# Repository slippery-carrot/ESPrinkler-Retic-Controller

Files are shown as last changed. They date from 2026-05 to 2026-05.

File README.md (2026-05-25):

# 🌱 ESPrinkler Retic Controller

An open-source, ESP32-based smart irrigation controller built with **ESPHome** and designed for seamless integration with **Home Assistant**.

ESPrinkler gives you full local control over your irrigation system—no cloud services, no subscriptions, and no reliance on external servers. All schedules are stored directly on the device, ensuring your system continues to run even if Home Assistant or network connectivity becomes unavailable.

---

## 🚀 Features

- Fully local operation (no cloud dependencies)  
- Home Assistant integration via ESPHome  
- Standalone operation with onboard schedule storage  
- Solid-state design with optically isolated outputs  
- Control up to **8 irrigation zones + pump/master valve**  
- Support for **up to 3 independent watering programs**  
- Flexible scheduling:
  - Day-of-week control  
  - Up to 4 start times per program  
  - Configurable zone durations and repeat cycles  
- LED indicators for system status and outputs  

---

## 🧠 How It Works

ESPrinkler operates using up to **three independent watering programs**, each of which defines:

- When watering occurs (days + start times)  
- Which zones are active  
- How long each zone runs  
- Whether the cycle repeats  

All configuration is done through **Home Assistant entities**, and once configured, the controller runs autonomously.

⚠️ Programs **do not prevent overlap automatically**, so you must ensure schedules don’t conflict.

---

## 🏗️ Hardware Overview

The controller is built around an **ESP32 (ESP32-DevKitC compatible)** and a custom PCB designed for irrigation control.

Key hardware characteristics:

- Compatible with 24VAC reticulation systems
- Solid-state solenoid switching  
- Isolated AC/DC sections
- Fused solenoid power output
- Terminal block wiring for:
  - Power input  
  - Pump/master valve  
  - 8 irrigation zones  
- Optional external LEDs for:
  - Wi-Fi status  
  - System status  

For full specifications, wiring diagrams, and pinouts, see:  
**[Hardware Specifications Wiki](../../wiki/Hardware-Specifications)**

---

## ⚡ Requirements

To build and use ESPrinkler, you’ll need:

- ESP32 Dev Board (ESP32-DevKitC compatible)  
- ESPrinkler PCB (assembled or DIY)  
- 24VAC transformer (~30VA recommended)  
- Fuse (M205 1A Quick Blow)  
- Suitable enclosure  
- Wiring/connectors for your installation  
- Home Assistant with ESPHome installed  

---

## 🛠️ Getting Started

### 1. Set Up ESPHome

Install and configure ESPHome in Home Assistant:  
https://esphome.io/guides/getting_started_hassio/

---

### 2. Prepare Firmware

- Copy the provided `secrets.yaml` values into your ESPHome setup  
- Import the `retic-controller.yaml` file into ESPHome (Add new device -> Import from file) 
- Update the substitutions (Wi-Fi, API key, device name, etc.)  

---

### 3. Flash the Device

- Click the 3 dots under the new configuration
- Click "install" and follow your preferred method to flash your ESP32
- I recommend choosing "manual download" and then navigate to [ESPHome Web](https://web.esphome.io/) to flash your device using the binary file
- Once flashed, the device will appear in Home Assistant

---

### 4. Wire the Hardware

- Connect 24VAC input  
- Connect solenoids (zones + common)  
- Install fuse  
- Optional: connect status LEDs  

⚠️ **Warning:** This involves working with mains/low-voltage AC systems. Follow all relevant electrical safety standards and regulations.
👉 See the **[Hardware Specifications Wiki](../../wiki/Hardware-Specifications)** for full wiring details and pinouts.

---

### 5. Configure in Home Assistant

Once the device is online:

- Enable one or more programs  
- Set watering days  
- Configure start times  
- Enable zones and durations
- An example [dashboard page .yaml file](https://github.com/slippery-carrot/ESPrinkler-Retic-Controller/blob/main/ESPHome/ESPrinkler_Dashboard_Example.yaml) has been provided as an example layout in Home Assistant

⚠️ **NOTE:** The example dashboard yaml uses [Mushroom Cards](https://github.com/piitaya/lovelace-mushroom), so make sure to install that if you want it to function.
👉 See the **[Home Assistant Entities Wiki](../../wiki/Home-Assistant-Entities)** for a full breakdown of all controls, sensors, and configuration options.

---

## 🌿 Program Basics

Each program requires:

- ✅ Program enabled  
- ✅ At least one watering day  
- ✅ At least one start time  
- ✅ At least one active zone with duration  

Optional settings:

- Repeat cycles (repeat full zone sequence)  

---

## 🏠 Home Assistant Integration

ESPrinkler exposes a full set of:

- **Controls** (start/stop, enable program, pause)  
- **Sensors** (current zone, time remaining, next cycle)  
- **Configuration entities** (days, times, durations, repeats)  
- **Diagnostics** (Wi-Fi signal, uptime, firmware, etc.)  

👉 Full details here:  
**[Home Assistant Entities Wiki](../../wiki/Home-Assistant-Entities)**

---

## 🧩 Project Structure

- Firmware: ESPHome YAML configuration and secrets example, including example dashboard layout  
- Hardware: Custom PCB design in KiCad and production files
- Documentation:
  - README (this file)  
  - Hardware Wiki  
  - Home Assistant Wiki  

---

## ⚠️ Important Notes

- Programs **can overlap** if configured incorrectly—this is not automatically prevented  
- Default start times may be active—always verify configuration  
- Ensure the transformer you choose is correctly sized for your solenoid load
- Always use appropriate fuse protection

---

## 🪰 Limitations, Issues, and Bugs
 - ESPrinkler requires connection to home assistant at least once in order to set its internal clock. Without this, it has no reference to the current time and date

## 🔗 Documentation

- 📘 **[Hardware Specifications Wiki](../../wiki/Hardware-Specifications)** – Pinouts, wiring, electrical specs  
- 📗 **[Home Assistant Entities Wiki](../../wiki/Home-Assistant-Entities)** – Entities, controls, automation  

---

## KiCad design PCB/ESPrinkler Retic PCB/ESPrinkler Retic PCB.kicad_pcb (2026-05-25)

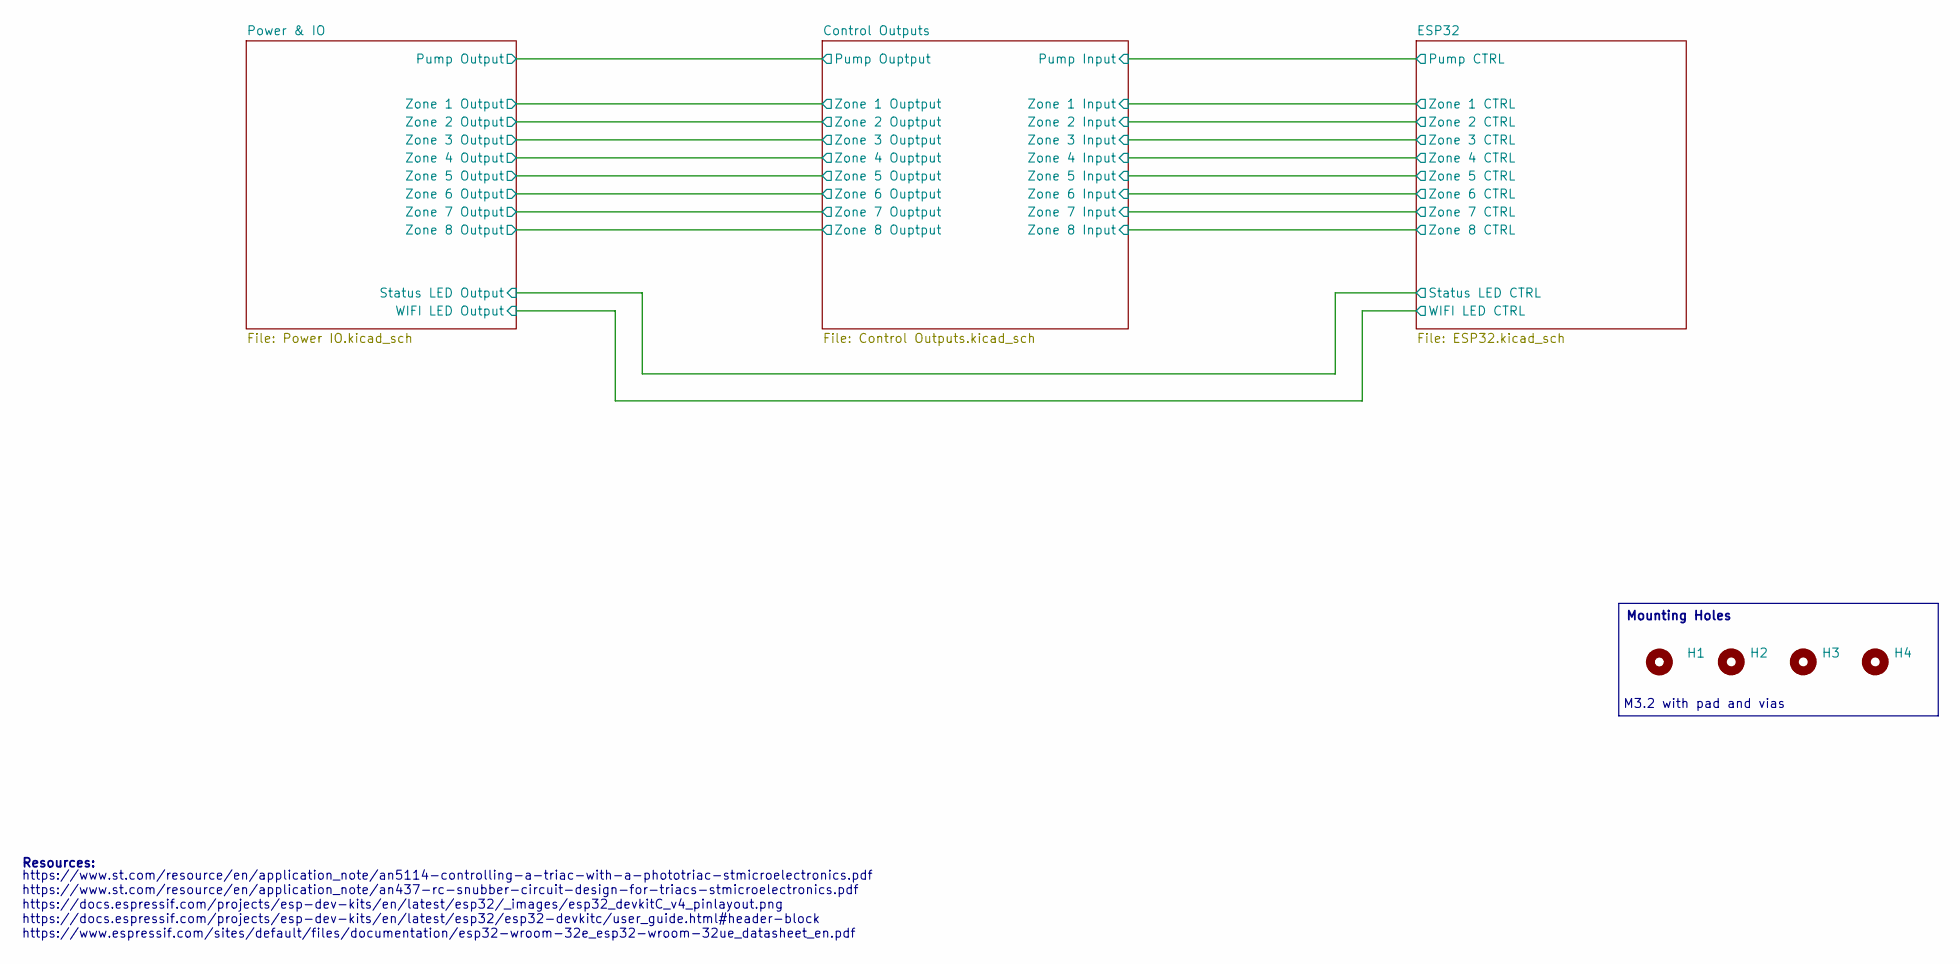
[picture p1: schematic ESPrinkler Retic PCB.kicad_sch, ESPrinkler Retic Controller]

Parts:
H1, H2, H3, H4: MountingHole; MountingHole_3.2mm_M3_Pad_Via

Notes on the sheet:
https://www.st.com/resource/en/application_note/an5114-controlling-a-triac-with-a-phototriac-stmicroelectronics.pdf https://www.st.com/resource/en/application_note/an437-rc-snubber-circuit-design-for-triacs-stmicroelectronics.pdf https://docs.espressif.com/projects/esp-dev-kits/en/latest/esp32/_ima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
M3.2 with pad and vias
Resources:
Mounting Holes

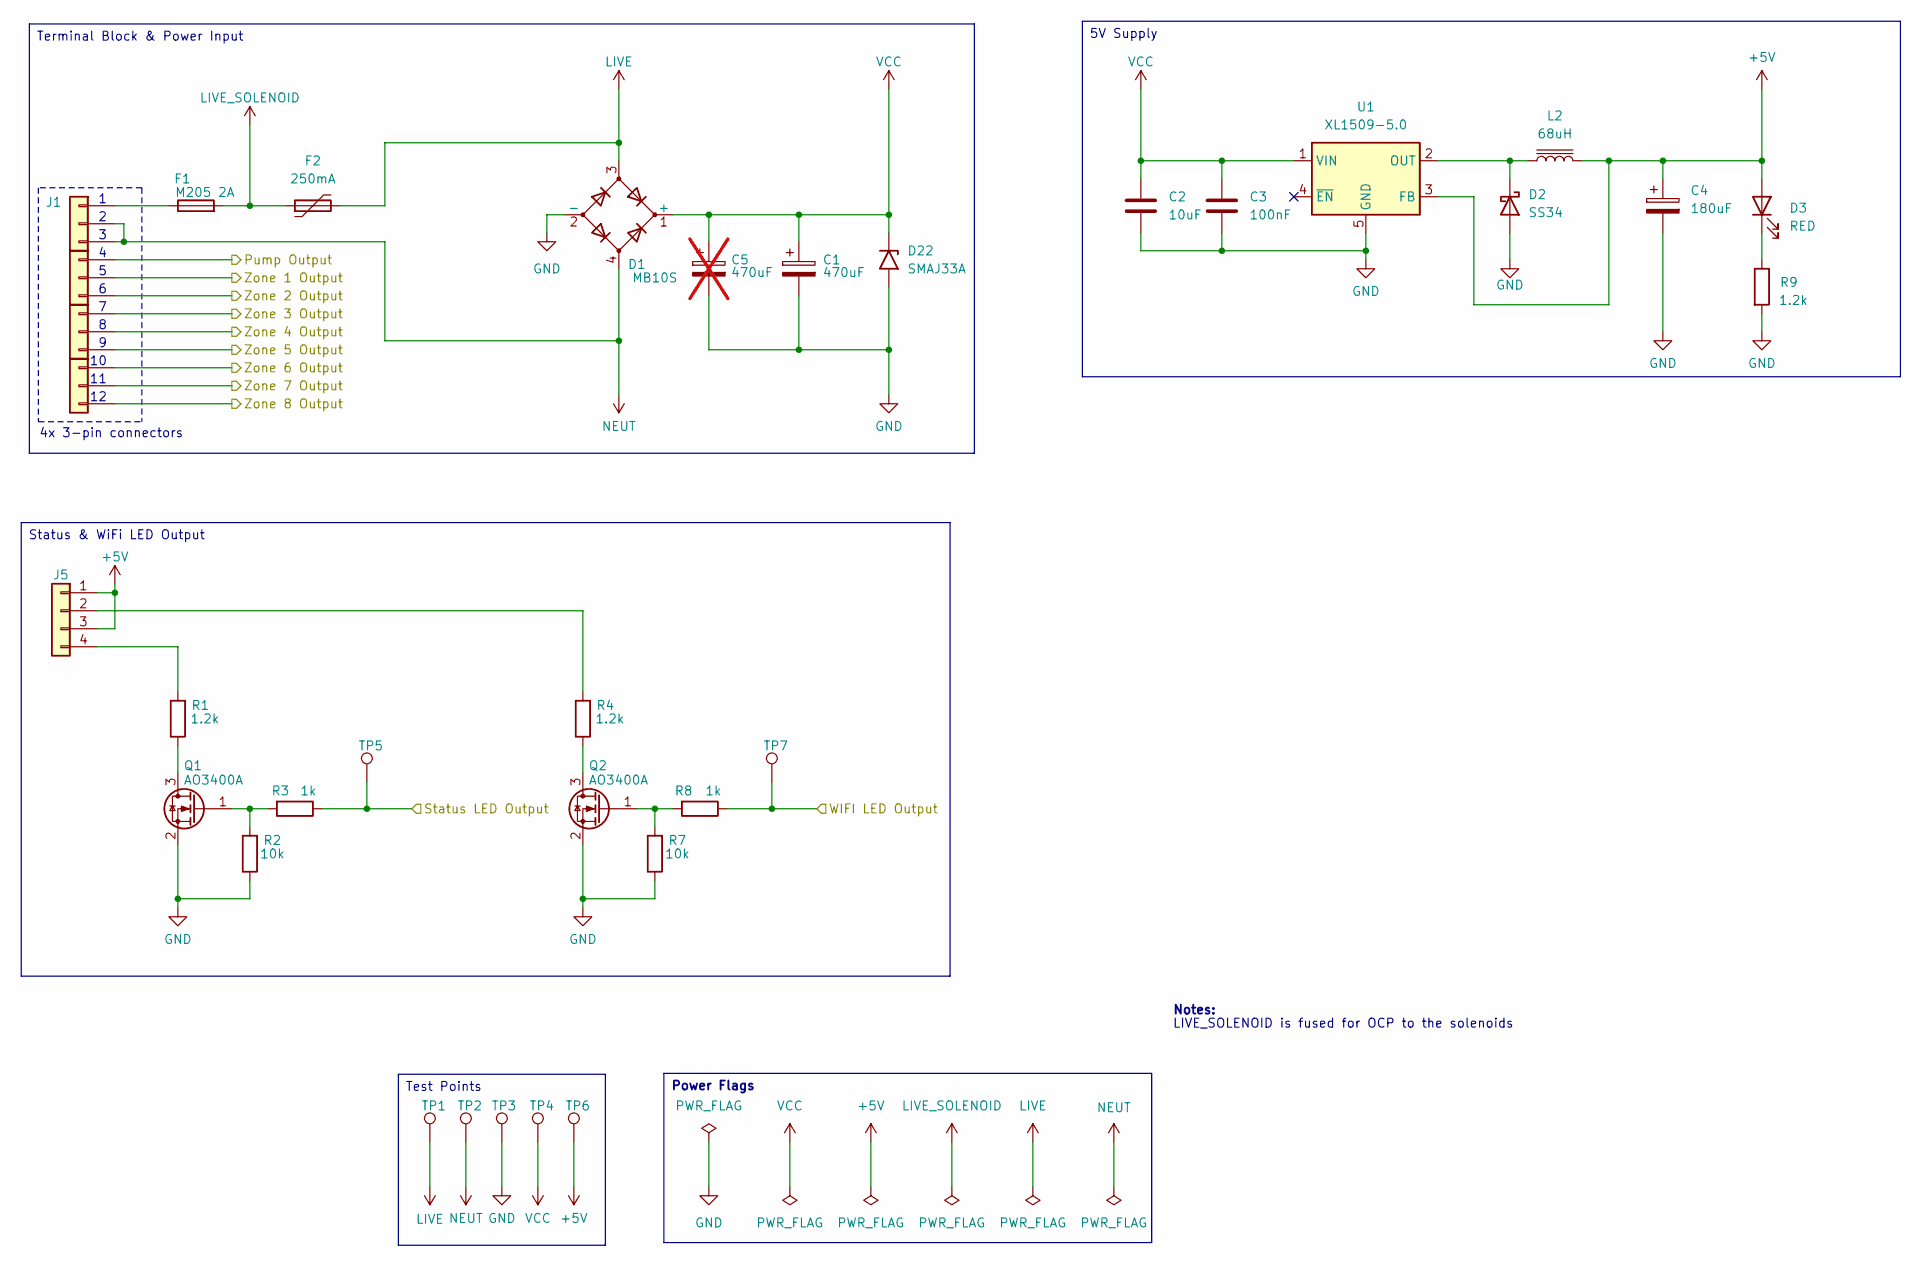
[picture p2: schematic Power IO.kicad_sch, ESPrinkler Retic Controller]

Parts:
C1: 470uF; CP_Radial_D10.0mm_P5.00mm; Manufacturer P/N PA63V470M10X17
C2: 10uF; C_1206_3216Metric; Manufacturer P/N CL31A106KBHNNNE
C3: 100nF; C_0805_2012Metric; Manufacturer P/N CL21B104KCFNNNE
C4: 180uF; CP_Radial_D6.3mm_P2.50mm; Manufacturer P/N PA25V180M6X7
C5: 470uF; CP_Radial_D10.0mm_P5.00mm; Manufacturer P/N PA63V470M10X17; not fitted
D1: MB10S; OnSemi_751EP_SOIC-4_3.9x4.725mm_P2.54mm; Manufacturer P/N MB10S-50MIL
D2: SS34; D_SMA; Manufacturer P/N SS34
D3: RED; LED_0603_1608Metric; Manufacturer P/N KT-0603R
D22: SMAJ33A; D_SMA; Manufacturer P/N SMAJ33A
F1: M205 2A; Fuseholder_Cylinder-5x20mm_Schurter_0031_8201_Horizontal_Op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; Manufacturer P/N PTF-15
F2: 250mA; Fuse_BelFuse_0ZRE0033FF_L11.4mm_W3.8mm; Manufacturer P/N RLVR240-025
J1, J2, J3, J4: DB910-7.62-3P-GN-S; DORABO_DB910-7.62-3P-GN-S_1x03_P7.62mm_Vertical; Manufacturer P/N DB910-7.62-3P-GN-S
J5: Conn_01x04; TerminalBlock_Phoenix_PT-1,5-4-5.0-H_1x04_P5.00mm_Horizontal; Manufacturer P/N DB301V-5.0-4P-BU-S
L2: 68uH; L_APV_ANR5045; Manufacturer P/N SMNR5040-680MT
Q1, Q2: AO3400A; SOT-23_Handsoldering; Manufacturer P/N AO3400A
R1, R4, R9: 1.2k; R_0805_2012Metric; Manufacturer P/N 0805W8F1201T5E
R2, R7: 10k; R_0805_2012Metric; Manufacturer P/N 0805W8F1002T5E
R3, R8: 1k; R_0805_2012Metric; Manufacturer P/N 0805W8F1001T5E
TP1, TP2, TP3, TP4, TP5, TP6, TP7: TestPoint; TestPoint_Pad_D1.5mm; Manufacturer P/N N/A
U1: XL1509-5.0; SOIC-8_3.9x4.9mm_P1.27mm; Manufacturer P/N XL1509-5.0E1

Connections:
+5V: C4.1, D3.2 (A), J5.1, J5.3, L2.2, TP6.1 (1_1), U1.3 (FB); also elsewhere on the board
/Control Outputs/Pump Ouptput: J2.1; also elsewhere on the board
/Control Outputs/Zone 1 Ouptput: J2.2; also elsewhere on the board
/Control Outputs/Zone 2 Ouptput: J2.3; also elsewhere on the board
/Control Outputs/Zone 3 Ouptput: J3.1; also elsewhere on the board
/Control Outputs/Zone 4 Ouptput: J3.2; also elsewhere on the board
/Control Outputs/Zone 5 Ouptput: J3.3; also elsewhere on the board
/Control Outputs/Zone 6 Ouptput: J4.1; also elsewhere on the board
/Control Outputs/Zone 7 Ouptput: J4.2; also elsewhere on the board
/Control Outputs/Zone 8 Ouptput: J4.3; also elsewhere on the board
/ESP32/Status LED CTRL: R3.1, TP5.1 (1_1); also elsewhere on the board
/ESP32/WIFI LED CTRL: R8.1, TP7.1 (1_1); also elsewhere on the board
GND: C1.2, C2.2, C3.1, C4.2, C5.2, D1.2 (-), D2.2 (A), D22.2 (A2), Q1.2 (S), Q2.2 (S), R2.1, R7.1, R9.2, TP3.1 (1_1), U1.5 (GND), U1.6 (GND), U1.7 (GND), U1.8 (GND); also elsewhere on the board
LIVE: D1.3, F2.2, TP1.1 (1_1)
LIVE_SOLENOID: F1.2, F2.1; also elsewhere on the board
NEUT: D1.4, J1.2, J1.3, TP2.1 (1_1); also elsewhere on the board
unnamed: D2.1 (K), L2.1, U1.2 (OUT)
unnamed: D3.1 (K), R9.1
unnamed: F1.1, J1.1
unnamed: J5.2, R4.2
unnamed: J5.4, R1.2
unnamed: Q1.3 (D), R1.1
unnamed: Q1.1 (G), R2.2, R3.2
unnamed: Q2.3 (D), R4.1
unnamed: Q2.1 (G), R7.2, R8.2
VCC: C1.1, C2.1, C3.2, C5.1, D1.1 (+), D22.1 (A1), TP4.1 (1_1), U1.1 (VIN)

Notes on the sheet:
4x 3-pin connectors
LIVE_SOLENOID is fused for OCP to the solenoids
Notes:
Status & WiFi LED Output
Test Points
Terminal Block & Power Input
5V Supply
Power Flags

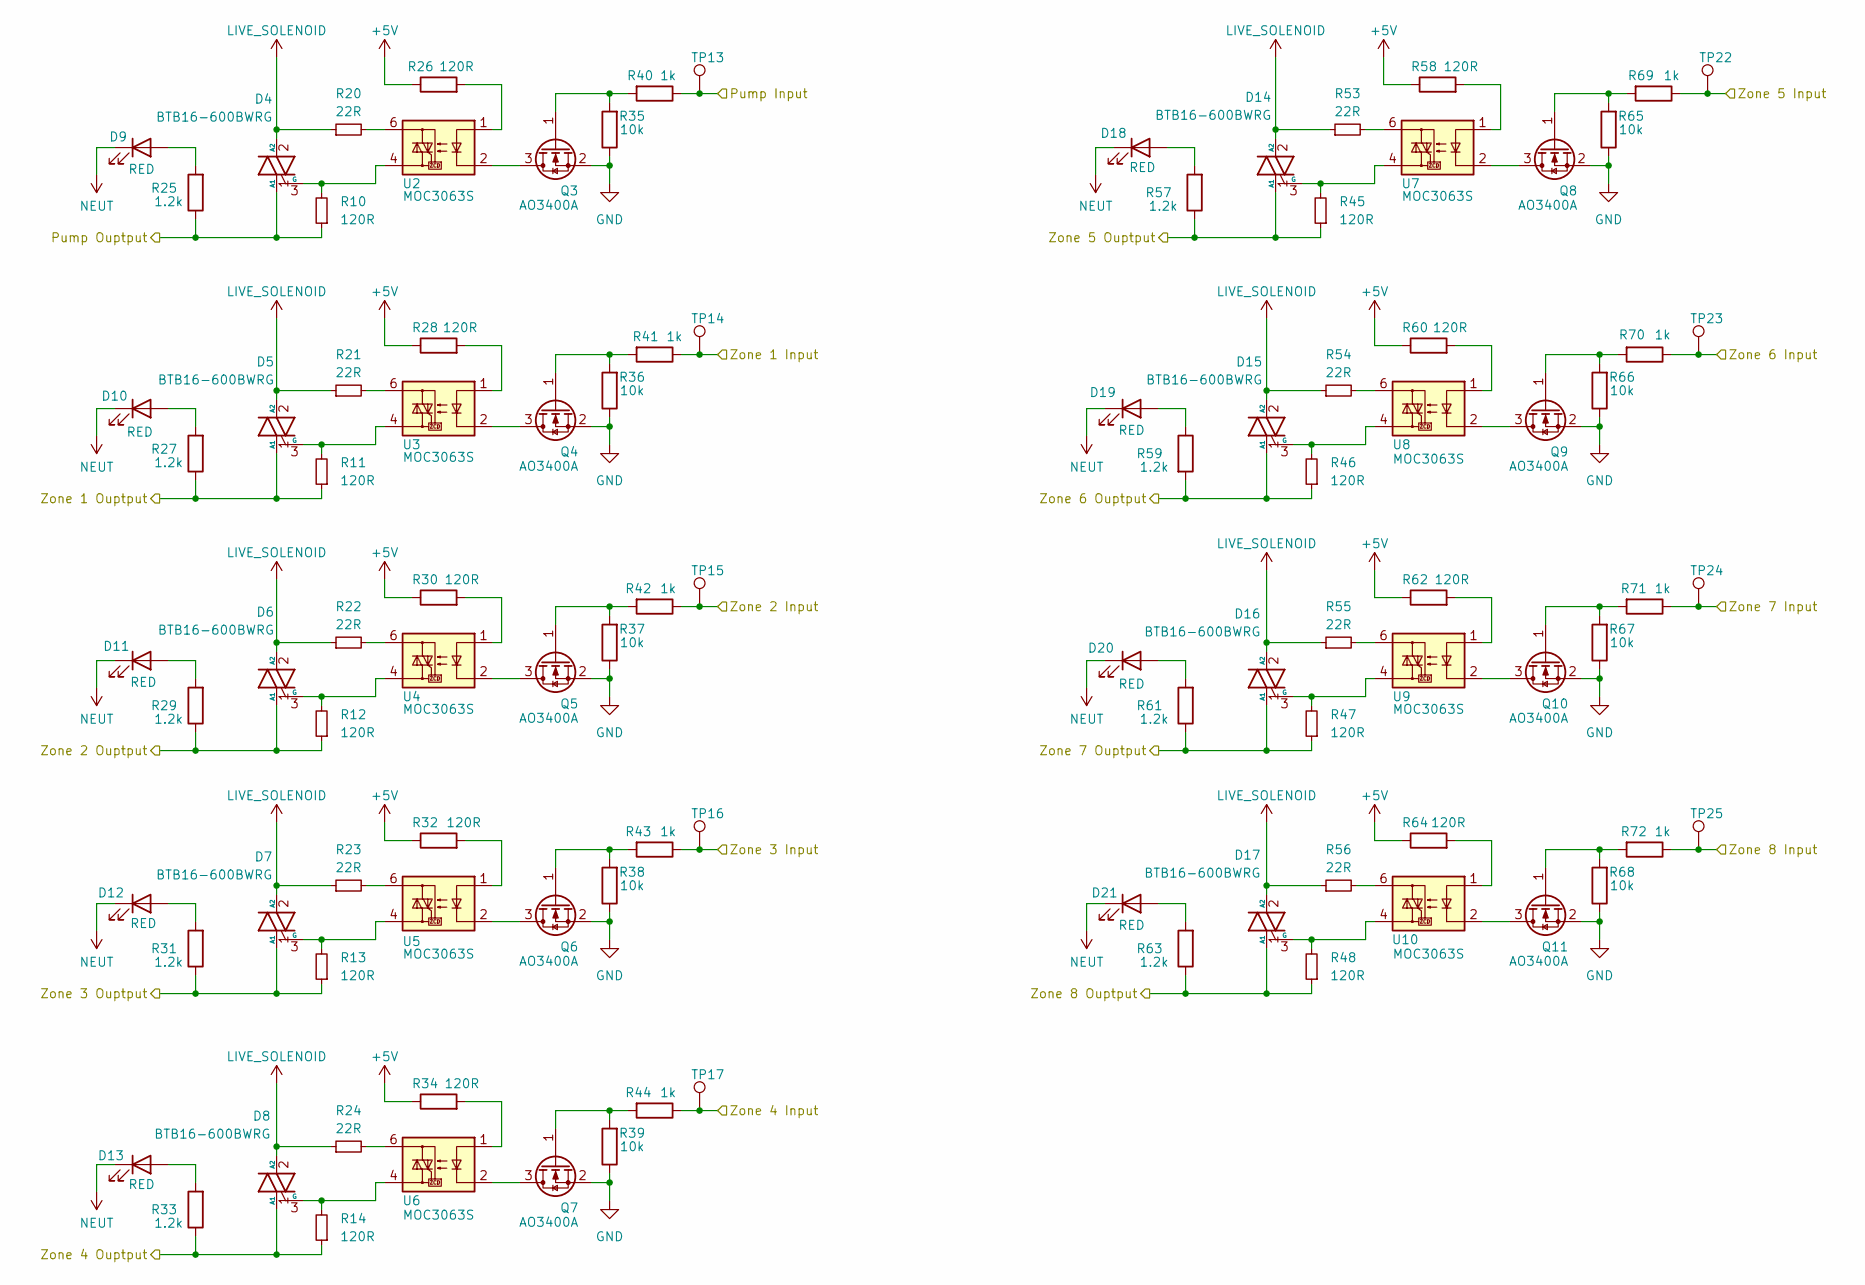
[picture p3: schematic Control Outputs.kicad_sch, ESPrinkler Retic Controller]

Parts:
D4, D5, D6, D7, D8, D14, D15, D16, D17: BTB16-600BWRG; TO-220-3_Horizontal_TabDown_NoHole; Manufacturer P/N BTB16-600BWRG
D9, D10, D11, D12, D13, D18, D19, D20, D21: RED; LED_0603_1608Metric; Manufacturer P/N KT-0603R
Q3, Q4, Q5, Q6, Q7, Q8, Q9, Q10, Q11: AO3400A; SOT-23_Handsoldering; Manufacturer P/N AO3400A
R10, R11, R12, R13, R14, R26, R28, R30, R32, R34, R45, R46, R47, R48, R58, R60, R62, R64: 120R; R_0805_2012Metric; Manufacturer P/N 0805W8F1200T5E
R20, R21, R22, R23, R24, R53, R54, R55, R56: 22R; R_0805_2012Metric; Manufacturer P/N 0805W8F220JT5E
R25, R27, R29, R31, R33, R57, R59, R61, R63: 1.2k; R_0805_2012Metric; Manufacturer P/N 0805W8F1201T5E
R35, R36, R37, R38, R39, R65, R66, R67, R68: 10k; R_0805_2012Metric; Manufacturer P/N 0805W8F1002T5E
R40, R41, R42, R43, R44, R69, R70, R71, R72: 1k; R_0805_2012Metric; Manufacturer P/N 0805W8F1001T5E
TP13, TP14, TP15, TP16, TP17, TP22, TP23, TP24, TP25: TestPoint; TestPoint_Pad_D1.5mm; Manufacturer P/N N/A
U2, U3, U4, U5, U6, U7, U8, U9, U10: MOC3063S; MOC306XS_LTO; Manufacturer P/N MOC3063S-TA1

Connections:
+5V: R26.1, R28.1, R30.1, R32.1, R34.1, R58.1, R60.1, R62.1, R64.1; also elsewhere on the board
/Control Outputs/Pump Input: R40.1, TP13.1 (1_1); also elsewhere on the board
/Control Outputs/Pump Ouptput: D4.1 (A1), R10.1, R25.1; also elsewhere on the board
/Control Outputs/Zone 1 Input: R41.1, TP14.1 (1_1); also elsewhere on the board
/Control Outputs/Zone 1 Ouptput: D5.1 (A1), R11.1, R27.1; also elsewhere on the board
/Control Outputs/Zone 2 Input: R42.1, TP15.1 (1_1); also elsewhere on the board
/Control Outputs/Zone 2 Ouptput: D6.1 (A1), R12.1, R29.1; also elsewhere on the board
/Control Outputs/Zone 3 Input: R43.1, TP16.1 (1_1); also elsewhere on the board
/Control Outputs/Zone 3 Ouptput: D7.1 (A1), R13.1, R31.1; also elsewhere on the board
/Control Outputs/Zone 4 Input: R44.1, TP17.1 (1_1); also elsewhere on the board
/Control Outputs/Zone 4 Ouptput: D8.1 (A1), R14.1, R33.1; also elsewhere on the board
/Control Outputs/Zone 5 Input: R69.1, TP22.1 (1_1); also elsewhere on the board
/Control Outputs/Zone 5 Ouptput: D14.1 (A1), R45.1, R57.1; also elsewhere on the board
/Control Outputs/Zone 6 Input: R70.1, TP23.1 (1_1); also elsewhere on the board
/Control Outputs/Zone 6 Ouptput: D15.1 (A1), R46.1, R59.2; also elsewhere on the board
/Control Outputs/Zone 7 Input: R71.1, TP24.1 (1_1); also elsewhere on the board
/Control Outputs/Zone 7 Ouptput: D16.1 (A1), R47.1, R61.1; also elsewhere on the board
/Control Outputs/Zone 8 Input: R72.1, TP25.1 (1_1); also elsewhere on the board
/Control Outputs/Zone 8 Ouptput: D17.1 (A1), R48.1, R63.1; also elsewhere on the board
GND: Q3.2 (S), Q4.2 (S), Q5.2 (S), Q6.2 (S), Q7.2 (S), Q8.2 (S), Q9.2 (S), Q10.2 (S), Q11.2 (S), R35.1, R36.1, R37.1, R38.1, R39.1, R65.1, R66.1, R67.1, R68.1; also elsewhere on the board
LIVE_SOLENOID: D4.2 (A2), D5.2 (A2), D6.2 (A2), D7.2 (A2), D8.2 (A2), D14.2 (A2), D15.2 (A2), D16.2 (A2), D17.2 (A2), R20.1, R21.1, R22.1, R23.1, R24.1, R53.1, R54.1, R55.1, R56.1; also elsewhere on the board
NEUT: D9.1 (K), D10.1 (K), D11.1 (K), D12.1 (K), D13.1 (K), D18.1 (K), D19.1 (K), D20.1 (K), D21.1 (K); also elsewhere on the board
unnamed: D4.3 (G), R10.2, U2.4
unnamed: D5.3 (G), R11.2, U3.4
unnamed: D6.3 (G), R12.2, U4.4
unnamed: D7.3 (G), R13.2, U5.4
unnamed: D8.3 (G), R14.2, U6.4
unnamed: D9.2 (A), R25.2
unnamed: D10.2 (A), R27.2
unnamed: D11.2 (A), R29.2
unnamed: D12.2 (A), R31.2
unnamed: D13.2 (A), R33.2
unnamed: D14.3 (G), R45.2, U7.4
unnamed: D15.3 (G), R46.2, U8.4
unnamed: D16.3 (G), R47.2, U9.4
unnamed: D17.3 (G), R48.2, U10.4
unnamed: D18.2 (A), R57.2
unnamed: D19.2 (A), R59.1
unnamed: D20.2 (A), R61.2
unnamed: D21.2 (A), R63.2
unnamed: Q3.3 (D), U2.2
unnamed: Q3.1 (G), R35.2, R40.2
unnamed: Q4.3 (D), U3.2
unnamed: Q4.1 (G), R36.2, R41.2
unnamed: Q5.3 (D), U4.2
unnamed: Q5.1 (G), R37.2, R42.2
unnamed: Q6.3 (D), U5.2
unnamed: Q6.1 (G), R38.2, R43.2
unnamed: Q7.3 (D), U6.2
unnamed: Q7.1 (G), R39.2, R44.2
unnamed: Q8.3 (D), U7.2
unnamed: Q8.1 (G), R65.2, R69.2
unnamed: Q9.3 (D), U8.2
unnamed: Q9.1 (G), R66.2, R70.2
unnamed: Q10.3 (D), U9.2
unnamed: Q10.1 (G), R67.2, R71.2
unnamed: Q11.3 (D), U10.2
unnamed: Q11.1 (G), R68.2, R72.2
unnamed: R20.2, U2.6
unnamed: R21.2, U3.6
unnamed: R22.2, U4.6
unnamed: R23.2, U5.6
unnamed: R24.2, U6.6
unnamed: R26.2, U2.1
unnamed: R28.2, U3.1
unnamed: R30.2, U4.1
unnamed: R32.2, U5.1
unnamed: R34.2, U6.1
unnamed: R53.2, U7.6
unnamed: R54.2, U8.6
unnamed: R55.2, U9.6
unnamed: R56.2, U10.6
unnamed: R58.2, U7.1
unnamed: R60.2, U8.1
unnamed: R62.2, U9.1
unnamed: R64.2, U10.1

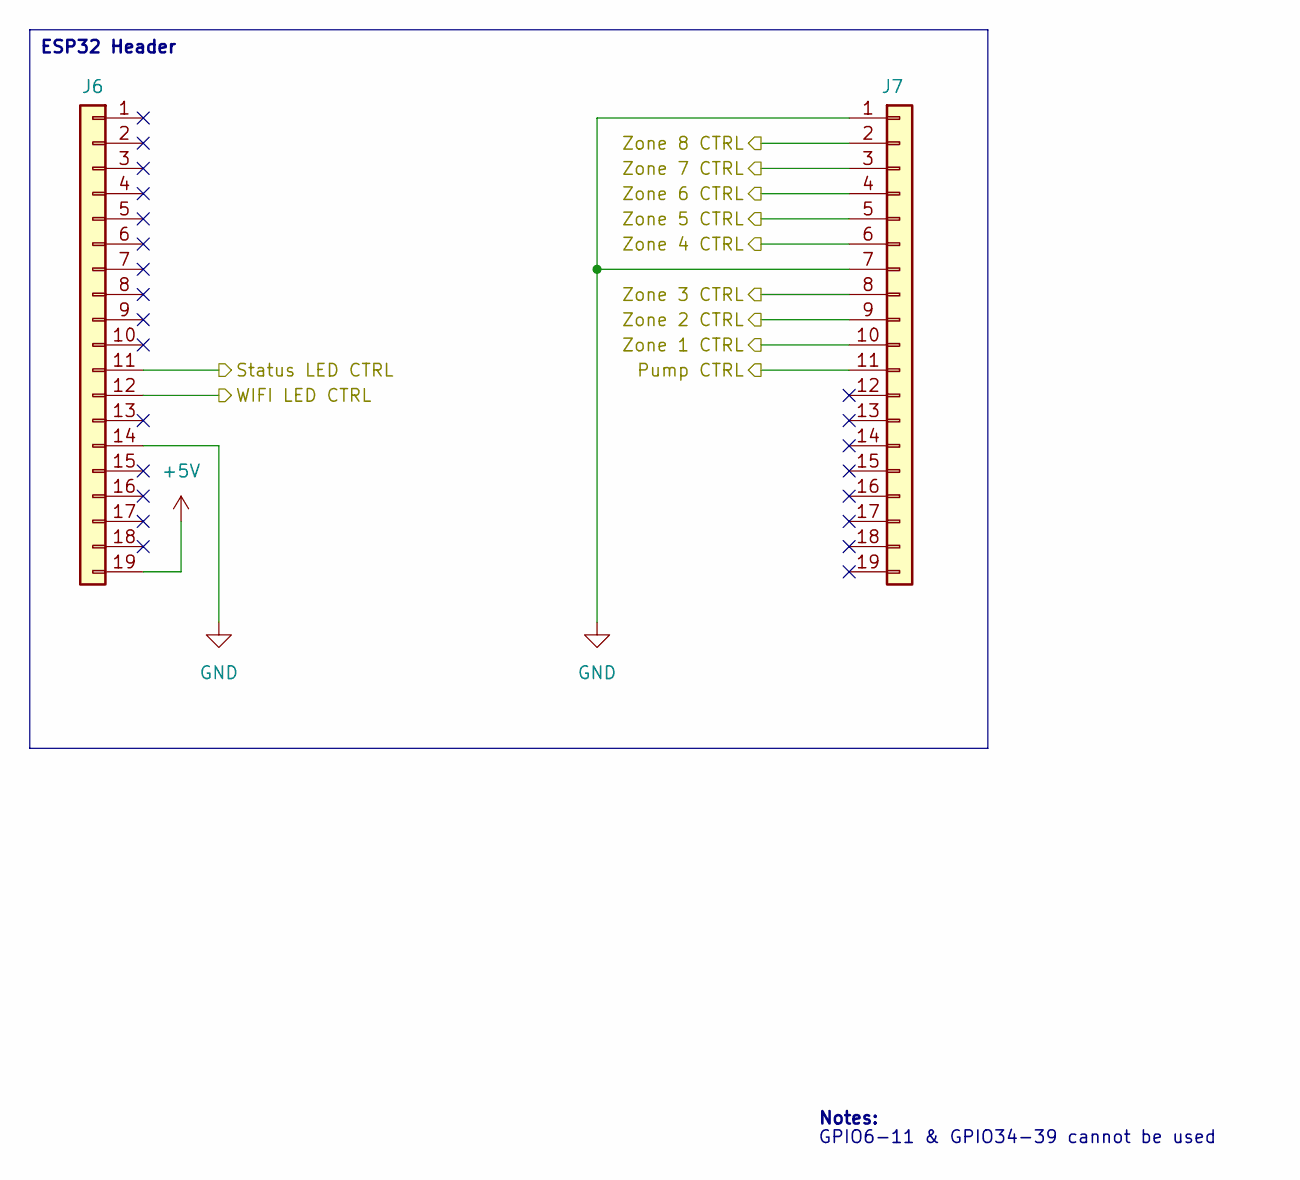
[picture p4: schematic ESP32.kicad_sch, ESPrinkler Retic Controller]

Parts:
J6, J7: Conn_01x19; PinSocket_1x19_P2.54mm_Vertical; Manufacturer P/N KH-2.54FH-1X19P-H8.5

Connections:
+5V: J6.19; also elsewhere on the board
/Control Outputs/Pump Input: J7.11; also elsewhere on the board
/Control Outputs/Zone 1 Input: J7.10; also elsewhere on the board
/Control Outputs/Zone 2 Input: J7.9; also elsewhere on the board
/Control Outputs/Zone 3 Input: J7.8; also elsewhere on the board
/Control Outputs/Zone 4 Input: J7.6; also elsewhere on the board
/Control Outputs/Zone 5 Input: J7.5; also elsewhere on the board
/Control Outputs/Zone 6 Input: J7.4; also elsewhere on the board
/Control Outputs/Zone 7 Input: J7.3; also elsewhere on the board
/Control Outputs/Zone 8 Input: J7.2; also elsewhere on the board
/ESP32/Status LED CTRL: J6.11; also elsewhere on the board
/ESP32/WIFI LED CTRL: J6.12; also elsewhere on the board
GND: J6.14, J7.1, J7.7; also elsewhere on the board

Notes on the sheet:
GPIO6-11 & GPIO34-39 cannot be used
Notes:
ESP32 Header

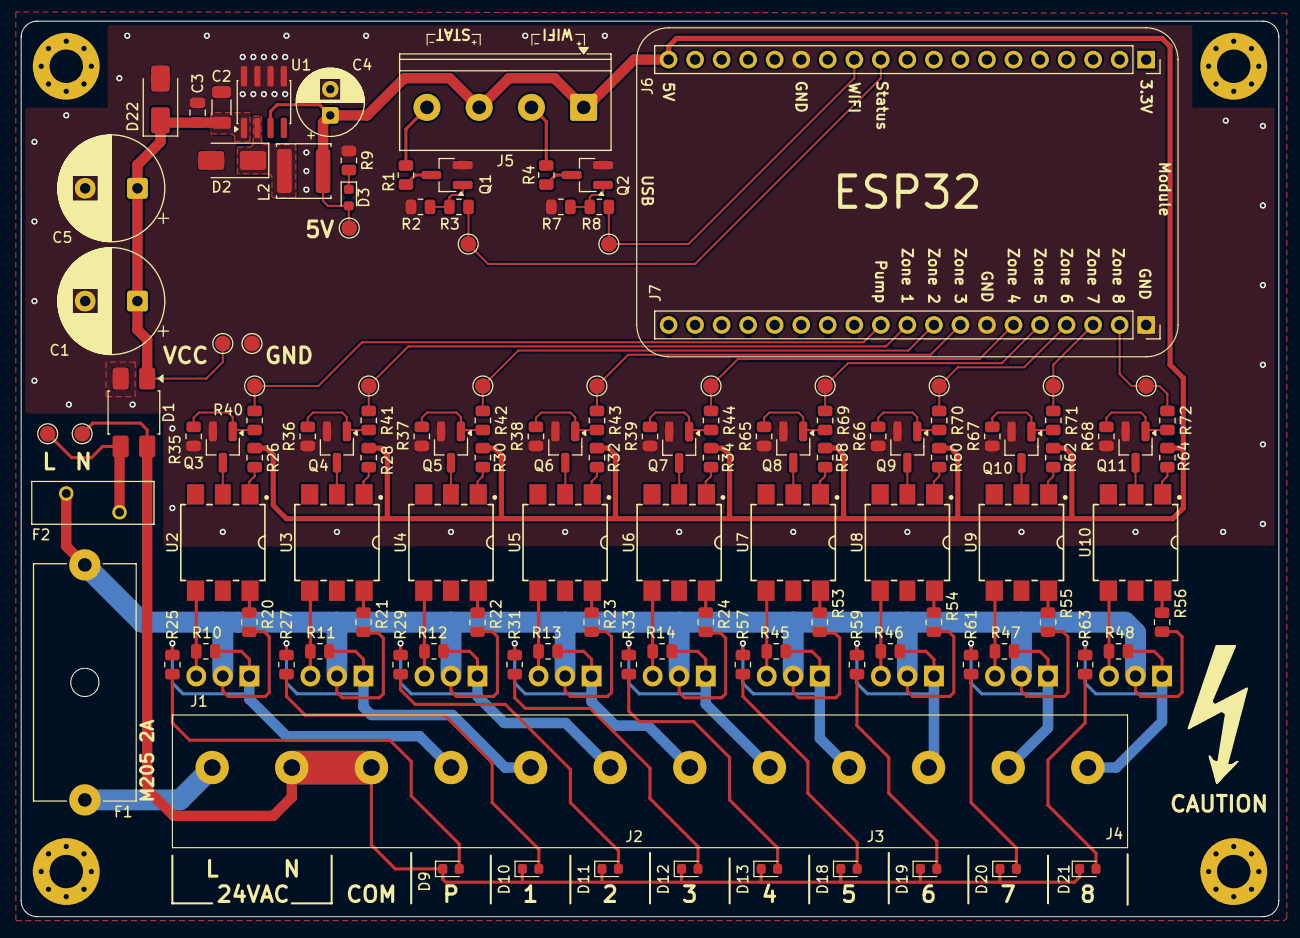
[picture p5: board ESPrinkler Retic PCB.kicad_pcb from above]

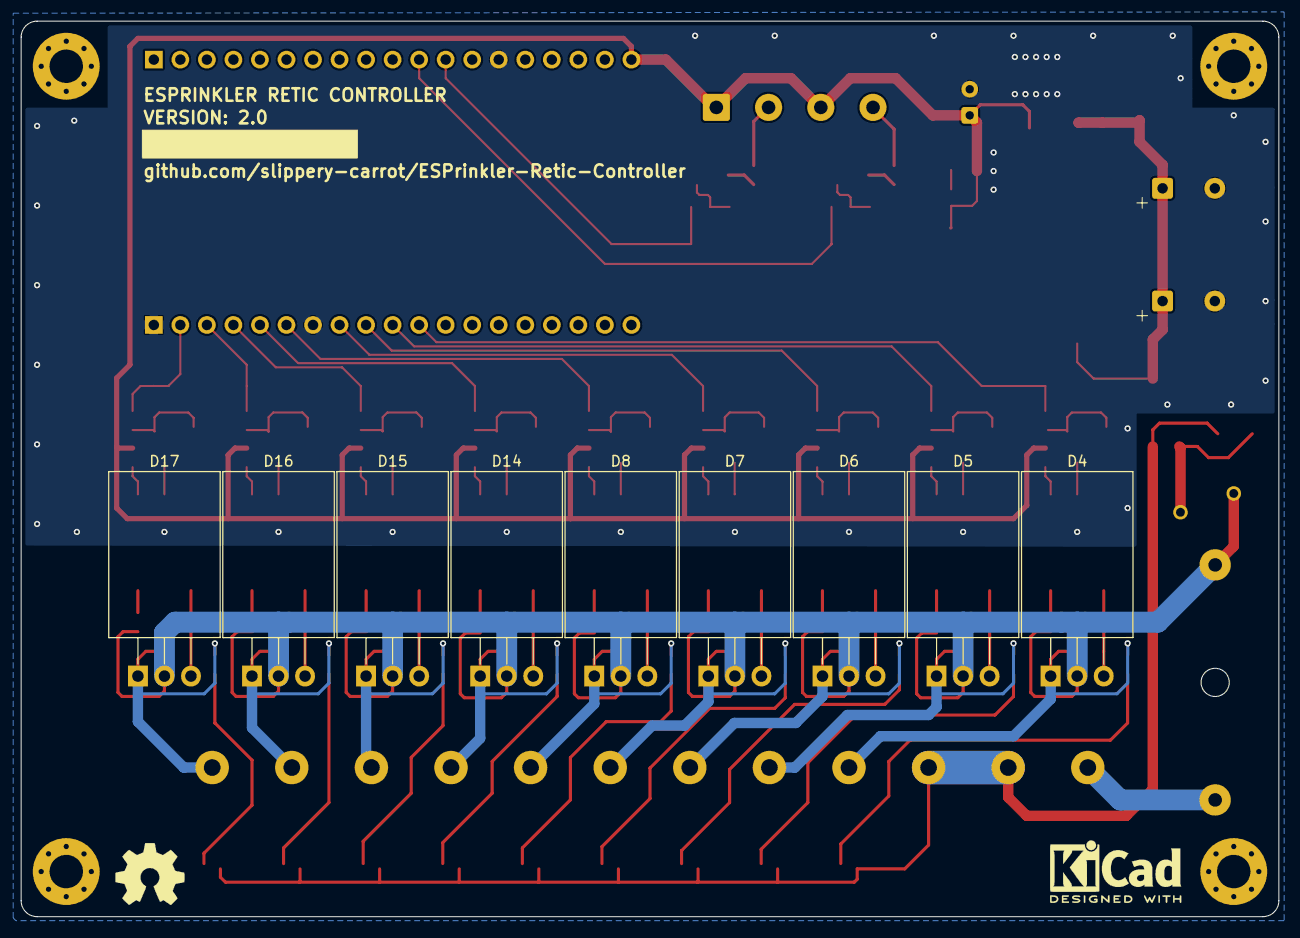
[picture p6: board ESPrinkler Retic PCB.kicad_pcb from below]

Board: 2 copper layers, 120.4 x 85.7 mm, 139 parts (9 on the bottom side), 89 nets.

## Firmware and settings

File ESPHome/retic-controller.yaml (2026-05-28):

# ================================================================
# ESPrinkler Reticulation Controller
# ---------------------------------------------------------------
# Project:       ESPHome-based Sprinkler Controller
# Description:   Controls 8 irrigation zones + main valve
#                - Configurable via Home Assistant
#                - Independent operation in case of Wi-Fi loss
#                - Adjustable sprinkler schedules for up to 3 separate programs
# Author:        Alexander Lauderdale
# GitHub:        https://github.com/slippery-carrot/ESPrinkler-Retic-Controller
# Version:       2.0.0
# Date:          2026-05-26
# ================================================================


###################################
# Substitutions 
###################################
substitutions:

  # Sensor update frequency
  sensor_update_frequency: 5s # Set how often the more critical sensors update, sensors with an interval not defined default to 60s

  # Interval for saving to flash
  flash_save_interval: 1min # Set how often variables are saved to flash
  
  # Keys and passwords
  api_key: !secret esprinkler_api_key # API key
  ota_password: !secret esprinkler_ota_password  # Over-the-air password
  ap_password: !secret esprinkler_ap_password   # Wi-fi AP password
  wifi_ssid: !secret wifi_ssid
  wifi_password: !secret wifi_password
  web_server_username: !secret esprinkler_ws_username
  web_server_password: !secret esprinkler_ws_password


  # Status LEDs GPIO assignments
  status_led_gpio: GPIO27
  wifi_led_gpio: GPIO14

  # Sprinkler Component variables
  duration_entity_mode: SLIDER  # Changes the integration input mode, recommend BOX or SLIDER 
  valve_overlap_setting: 3s     # Set the overlap between two valves, helps reduce banging
  pump_start_delay_setting: 3s  # Set the delay from when a zone valve opens, and the main valve opens
  pump_stop_delay_setting: 3s   # Set the delay from when the pump is turned off to when the last valve closes to reduce pressure in the line
  repeat_cycle_initial: '0'     # Configure the initial setting for the repeat cycles
  repeat_cycle_max: '5'         # Configure the max setting for the repeat cycles
  repeat_cycle_min: '0'         # Configure the min setting for the repeat cycles

  # Valve & Pump (Main Valve) GPIO's
  # Enter the GPIO assignments for the pump and each zone below
  pump_gpio: GPIO17
  zone_1_gpio: GPIO5
  zone_2_gpio: GPIO18
  zone_3_gpio: GPIO19
  zone_4_gpio: GPIO21
  zone_5_gpio: GPIO3
  zone_6_gpio: GPIO1
  zone_7_gpio: GPIO22
  zone_8_gpio: GPIO23


  # True if your relay board is active low (GND trigger)
  # False if your relay board is active high (VCC trigger)
  relay_inversion: 'False'

  # Version info
  esprinkler_sw_version: "V1.1.0"

  # Names and name IDs
  project_author: "Alexander Lauderdale"
  name_of_device: "esprinkler-retic-controller"   # Name of the device
  name_of_project: esprinkler                   # Name of the project
  namespace_of_project: ${project_author}.${name_of_device}
  friendly_name: "ESPrinkler Retic Controller"  # Friendly name

###################################
# Global variables
###################################
globals:
  # Program 1 "skip-next-day" target date (YYYY-MM-DD). 0 means unset.
  - id: prog1_skip_year
    type: int
    restore_value: yes
    initial_value: '0'
  - id: prog1_skip_month
    type: int
    restore_value: yes
    initial_value: '0'
  - id: prog1_skip_day
    type: int
    restore_value: yes
    initial_value: '0'


###################################
# Board setup
###################################
esp32:
  board: esp32dev
  framework:
    type: esp-idf
    version: recommended

###################################
# ESPHome settings
###################################
esphome:
  name: $name_of_device
  friendly_name: $friendly_name
  project: 
    name: $namespace_of_project
    version: $esprinkler_sw_version

  # Runs when device boots
  on_boot: 
    priority: -100
    then:
      ###
      # Code to run on boot goes here
      ###

###################################
# ESP Preferences
###################################
preferences:
  # Flash write interval
  flash_write_interval: $flash_save_interval

###################################
# Enable logging
###################################
logger:
  level: INFO
###################################
# Enable Home Assistant API
###################################
api:
  encryption:
    key: $api_key

###################################
# Over the air updates
###################################
ota:
  platform: esphome
  id: my_ota
  password: $ota_password

###################################
# Wifi settings
###################################
wifi:
  ssid: $wifi_ssid
  password: $wifi_password

  # Enable fallback hotspot (captive portal) in case wifi connection fails
  ap:
    ssid: $friendly_name
    password: $ap_password
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

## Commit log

2025-02-19 Begin setup of repo, add folders, create PCB project, add YAML file
    [ESPrinkler Retic PCB.kicad_pcb, ESPrinkler Retic PCB.kicad_sch, retic-controller.yaml]
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2025-03-05 Remove part choices due to schematic setup issue, will redo this at some point.
    Add headers for ESP32
    [ESPrinkler Retic PCB.kicad_sch]
2025-03-06 Added code to control a Wifi status LED and a general status LED.
    Added above onto schematic, start working on ESP32 dev kit pinout
    [ESPrinkler Retic PCB.kicad_sch, retic-controller.yaml]
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2025-03-17 Lay out control schematic and begin choosing parts
    Source parts for existing symbols on the control schematic after laying out pump and zone circuits
    [Control Outputs.kicad_sch, Power IO.kicad_sch]
2025-03-17 Continue parts sourcing for existing components
    Continue to source parts from LCSC for the existing components.
    [Control Outputs.kicad_sch, ESP32.kicad_sch, Power IO.kicad_sch]
2025-03-22 Initial schematic design completed
    Finish initial schematic design and source all required components. DRC completed with only minor warnings (regarding net names, no worries). Move on to begin PCB design
    [Control Outputs.kicad_sch, ESP32.kicad_sch, ESPrinkler Retic PCB.kicad_sch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]
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2025-03-24 Update file to suit PCB
    Changed GPIOs for solenoids, change relay inversion to false
    [retic-controller.yaml]
2025-03-24 Begin PCB layout
    Need to find a better connector for power and outputs
    [ESPrinkler Retic PCB.kicad_pcb]
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2025-04-02 Found potential solution for main header connector
    Choose main header solution, create footprint for header, update SCH and PCB
    [ESPrinkler Retic PCB.kicad_pcb, Power IO.kicad_sch]
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2025-04-07 PCB and SCH work
    Fix symbol issue for mosfet.
    Continue PCB design layout
    [Control Outputs.kicad_sch, ESPrinkler Retic PCB.kicad_pcb, Power IO.kicad_sch]
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2025-05-04 Continue PCB design
    Change footprint of triacs to include solder tab for securing package to PCB and heat dissipation.
    Change footprint of optocoupler for better solder mask outlines and smaller pads.
    [Control Outputs.kicad_sch, ESP32.kicad_sch, ESPrinkler Retic PCB.kicad_pcb]
2025-05-18 Change LED output indicator
    Change LED indication for each channel to be powered off 24VAC line post triac instead of off the MOSFET. Easier PCB design and effectively same result
    [Control Outputs.kicad_sch]
2025-05-19 Continue PCB layout
    Final placements and traces of components for first revision.
    [Control Outputs.kicad_sch, ESPrinkler Retic PCB.kicad_pcb, MOC306XS_LTO.step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]
2025-05-31 Modify SCH
    Remote ~ from datasheet section and spelling mistake on parts list.
    Swap status and wifi led control GPIOs for easier PCB traces
    [ESP32.kicad_sch, Power IO.kicad_sch]
2025-05-31 PCB touch ups
    Add more detail to PCB.
    Clean up traces.
    Add 3D model for full bridge rectifier.
    [ESPrinkler Retic PCB BOM.csv, ESPrinkler Retic PCB.kicad_pcb, MB10S.STEP]
2025-06-09 Update Schematics
    For all, update title block information.
    Power IO:
    - Change PTC fuse footprint reference
    - Add part info for J1
    Control Outputs:
    - Add notes and box areas of schematic for clarity
    [Control Outputs.kicad_sch, ESP32.kicad_sch, ESPrinkler Retic PCB.kicad_sch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]
2025-06-09 Modify PCB layout & Export MFG files
    Modified PCB layout after exporting mfg files and noticing some parts issues.
    [ESPrinkler Retic PCB BOM.csv, ESPrinkler Retic PCB.kicad_pcb, designators.csv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]
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2025-06-10 Change FB array resistors
    Change FB resistor values for step down converter, changing output voltage to be much closer to 5V.
    Footprint of resistors changed.
    [BOM.csv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]
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2025-06-18 Prepare for V1.0 production
    Export fab files for PCB manufacturing and parts ordering
    [BOM.csv, Control Outputs.kicad_sch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]
2025-07-09 PCB version 1.1 following peer review
    PTC in line with live, previously shorted between live and neutral.
    Added boxes around sections on schematic for better readability.
    Modified terminal block silkscreen to make more sense
    Modified routing of 5V power to to reduce tunnels and traces on bottom plane.
    [Control Outputs.kicad_sch, ESP32.kicad_sch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]
2025-07-11 Continue V1.1 modifications
    Round off corners on PCB
    Remove solder mount for triacs, unnecessary addition. Can use adhesive if required to secure triacs.
    Remove unnecessary vias between top and bottom ground planes
    [Control Outputs.kicad_sch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]
2025-07-12 Change SMPS voltage divider
    Somehow managed to miscalculate the voltage divider resistor values to get 5V, getting 7V.
    Change resistor values, change to 0805 footprint.
    [ESPrinkler Retic PCB-B_Cu.gbr, ESPrinkler Retic PCB-B_Mask.gbr, ESPrinkler Retic PCB-B_Paste.gbr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]
2025-07-12 Fix LED outputs and GPIO assignments
    Get LED outputs working correctly, fix GPIO assignments to match PCB
    [retic-controller.yaml]
2025-07-14 Update PCB and SCH for snubber circuit DNF
    Snubber circuit is drawing too much power, capacitor and resistor values need to be looked at.
    Not including the circuit for the time being.
    Added alternate part for resistor, 0 ohm jumper.
    DNF capacitor in snubber circuit for each output.
    [Control Outputs.kicad_sch, ESP32.kicad_sch, ESPrinkler Retic PCB.kicad_pcb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]
2025-10-03 Begin working on V1.1
    Starting to add additional features.
    Coming up:
    Make sprinkler component valve and pump settings adjustable.
    Add a "skip next planned day" toggle switch
    [retic-controller.yaml]
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2026-01-04 WIFI LED logic and logging
    Fixed WIFI LED logic
    Minor spacing and wording changes
    [retic-controller.yaml]
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2026-01-04 Migrate settings and controls to config section
    Set anything relating to config to be as such so the entity loads as "config". Reduces items in "Control".
    [retic-controller.yaml]
2026-01-04 Fix pause feature
    Change "start" button to resume_or_start_full_cycle so that pause feature will work correctly
    [retic-controller.yaml]
2026-01-04 Move Main Start/Stop
    Had the main start/stop button moved to config, but makes more sense to keep it under controls
    [retic-controller.yaml]
2026-04-07 Update retic-controller.yaml
    Made all zone switches internal only
    Change comment for "internal: True".
    [retic-controller.yaml]
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2026-05-01 Remove snubber and bring Kicad V10 update
    Remove snubber from triac driver as its not required.
    Attempt to start migrating to Kicad V10
    [Control Outputs.kicad_sch, ESP32.kicad_sch, ESPrinkler Retic PCB.kicad_pcb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]
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2026-05-09 Change DC-DC converter & PCB routing
    Previous DC-DC converter max input voltage was close to VIN. Changed out for 40V rated input, and a simpler design.
    Also re-routed 5V rail to top layer to reduce layer swapping using vias for power lines
    [Control Outputs.kicad_sch, ESPrinkler Retic PCB.kicad_pcb, Power IO.kicad_sch]
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2026-05-09 Start updating models
    Updating models since moving to kicad 10.
    Will begin migrating to project library entirely
    [ESPrinkler Retic PCB.kicad_pcb]
2026-05-10 Labelling as V2.0
    Repo needs to change, I have been using it poorly. V2.0 will be the next "main branch". After that, forks will be used instead
    Also in this commit, I have updated the custom footprints and updated the links to them in the project.
    [Control Outputs.kicad_sch, ESP32.kicad_sch, ESPrinkler Retic PCB.kicad_pcb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]
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2026-05-24 Complete production files
    Production files correct for JLCPCB & LCSC.
    Delete raw files, keep compressed production file.
    [ESPrinkler Retic PCB BOM.csv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]
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
